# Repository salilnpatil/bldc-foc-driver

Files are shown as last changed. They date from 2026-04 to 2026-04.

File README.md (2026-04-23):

# BLDC Field-Oriented Control Driver

A custom three-phase inverter board and closed-loop firmware for driving a brushless DC (BLDC) motor using **Field-Oriented Control (FOC)**. Developed as my final-year B.Tech thesis and deployed as the pitch-axis actuator of a gimbal demonstrator: an external RC-style PWM signal commands a target angle, and the motor tracks it smoothly through a 3:1 gear reduction.

<p align="center">
  Driver tracking an external PWM setpoint on a BLDC gimbal
</p>

## Stack at a glance

| Layer | Choice |
| --- | --- |
| MCU | STM32G431 (Cortex-M4F + CORDIC coprocessor) |
| Commutation | 6-PWM, voltage-mode FOC ([SimpleFOC](https://simplefoc.com/)) |
| Position sensor | MA730 14-bit magnetic encoder (SPI) |
| Power stage | 3× half-bridge, TI N-channel MOSFETs |
| Setpoint input | RC-style PWM (timer input capture) |
| PCB tool | Autodesk EagleCAD |
| Bus voltage | 12 V (nominal) |

## Visuals

| PCB layout | Wiring diagram |
| --- | --- |
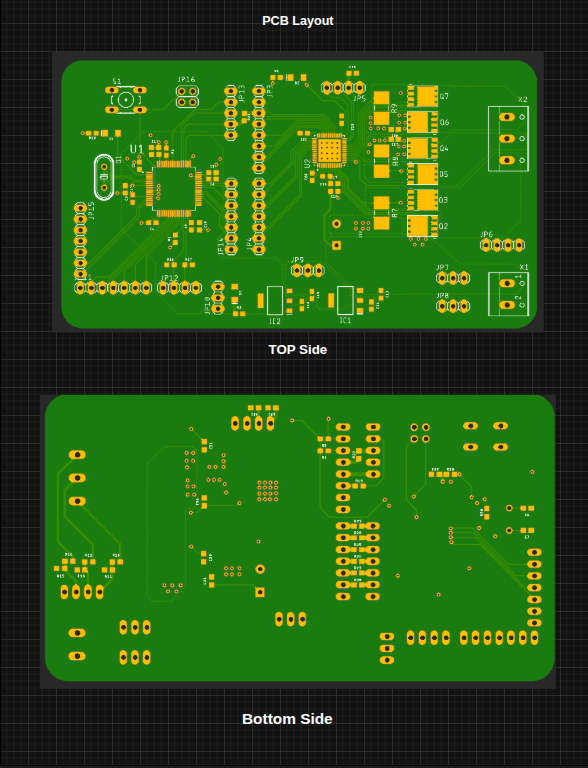
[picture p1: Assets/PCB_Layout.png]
PCB layout
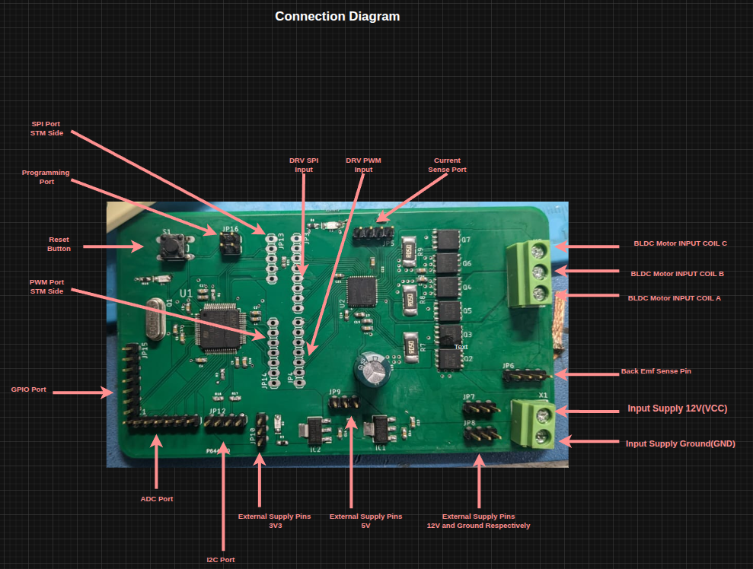
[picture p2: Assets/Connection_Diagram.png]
Wiring
|  |  |

Communication interface:

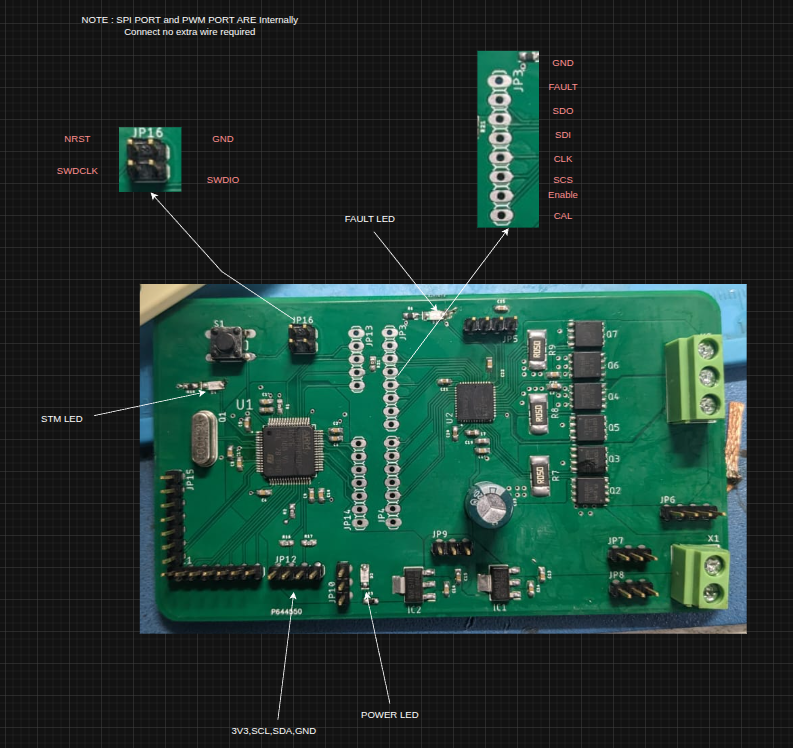
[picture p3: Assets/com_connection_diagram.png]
Communication wiring


## Repository layout

```
.
├── Assets/                              Demo GIF, connection diagrams, PCB render, final paper
├── Hardware_assets/
│   ├── Design_FIle(EagleCad)/           EagleCAD .brd + .sch sources
│   ├── Schematic/                       Exported PDF schematic
│   ├── Gerber_file/                     Fabrication-ready Gerbers (.zip)
│   └── BOM_&_Component_selection/       MOSFET trade-off spreadsheet
├── Firmware/
│   └── bldc-doc-driver/                 Arduino sketch (SimpleFOC on STM32G4)
└── README.md
```

## Hardware design

The board is a three-phase inverter built around three half-bridges of TI N-channel power MOSFETs, with an MA730 magnetic encoder front-end and a PWM-input pin exposed to an off-board receiver. A mechanical limit switch on the pitch axis provides a repeatable zero for homing.

**MOSFET selection** — the workbook in `Hardware_assets/BOM_&_Component_selection/` compares two TI candidates evaluated for the low-side/high-side switches:

| Part | Vds | Id | Rds(on) max | Qg | Notes |
| --- | --- | --- | --- | --- | --- |
| `CSD18510Q5B` | 40 V | 42 A | 1.2 mΩ | 118 nC | Lower Qgd, lower voltage headroom |
| `CSD18536KCS` | 60 V | 200 A | 1.3 mΩ | 108 nC | Higher Vds margin, much higher current rating |

Both sit at roughly 1.2–1.3 mΩ Rds(on), so the choice comes down to voltage headroom above the 12 V bus and thermal budget rather than conduction loss.

**Design artefacts**

- EagleCAD sources — [`Hardware_assets/Design_FIle(EagleCad)/Layout_Design_File.sch`](Hardware_assets/Design_FIle(EagleCad)/Layout_Design_File.sch), [`Schematic_Design_File.brd`](Hardware_assets/Design_FIle(EagleCad)/Schematic_Design_File.brd)
- Schematic PDF — [`Hardware_assets/Schematic/Final_Schematic.pdf`](Hardware_assets/Schematic/Final_Schematic.pdf)
- Gerbers — [`Hardware_assets/Gerber_file/Final_Gerber_File.zip`](Hardware_assets/Gerber_file/Final_Gerber_File.zip)

## Firmware

Sketch: [`Firmware/bldc-doc-driver/bldc-doc-driver.ino`](Firmware/bldc-doc-driver/bldc-doc-driver.ino).

**Control law** — SimpleFOC angle-control cascade: `angle (P) → velocity (PI) → q-axis voltage`. Torque mode is `TorqueControlType::voltage`, pole pairs are set to 7, and the motor voltage limit is clamped to `V_PSU / 2` for headroom.

**Parameters** (from the sketch)

| Define / field | Value |
| --- | --- |
| `V_PSU`, `V_LIMIT` | 12.0 V |
| `GEAR_REDUCTION` | 3 (pitch axis) |
| `ACCESSIBLE_ANGLE` | 3.00 rad of mechanical pitch travel |
| `PWM_IN_MIN` / `PWM_IN_MAX` | 4.94 % / 10.06 % duty (≈1.0–2.0 ms pulses) |
| `PID_velocity` P / I / D | 0.2 / 4 / 0 |
| `P_angle.P` | 10 |
| `velocity_limit` | 50 rad/s |

**Startup sequence**

1. Bring up the debug serial (`Serial3`, 115200), the STM32G4 CORDIC unit, the PWM input capture, and the MA730 sensor.
2. Configure driver + motor, run SimpleFOC `initFOC()` electrical alignment.
3. **Homing** — drive the motor slowly toward the limit switch; when it trips, snapshot the encoder angle as `max_angle`, compute `min_angle = max_angle − (ACCESSIBLE_ANGLE × GEAR_REDUCTION)`.
4. Build a linear mapper from input PWM duty `[4.94 %, 10.06 %]` onto `[min_angle, max_angle]`.

**Main loop** — `motor.loopFOC()` runs the current/voltage inner loop; each iteration the PWM-input duty is sampled, mapped to a target angle, clamped to the calibrated travel, and passed to `motor.move(target_angle)`.

### Library dependencies

- [SimpleFOC](https://github.com/simplefoc/Arduino-FOC) — `BLDCMotor`, `BLDCDriver6PWM`
- [SimpleFOC Drivers](https://github.com/simplefoc/Arduino-FOC-drivers) — `MagneticSensorMA730`, `STM32PWMInput`, `STM32G4CORDICTrigFunctions`, `STM32FlashSettingsStorage`
- [Arduino core for STM32 (stm32duino)](https://github.com/stm32duino/Arduino_Core_STM32) — board target: **Generic STM32G4 series / STM32G431xx**

### Build & flash (Arduino IDE)

1. Install Arduino IDE 2.x and the **STM32** boards package following stm32duino's instructions.
2. From Library Manager, install `SimpleFOC` and `SimpleFOC Drivers`.
3. Open `Firmware/bldc-doc-driver/bldc-doc-driver.ino`.
4. Board → *Generic STM32G4 series*; part → *STM32G431xx*; upload method → *STM32CubeProgrammer (SWD)* via an ST-Link.
5. Compile and flash.

### Known gaps / roadmap

- **STM32CubeIDE port** — planned. A HAL/LL implementation in STM32CubeIDE (native 6-PWM timer configuration, ADC-based phase current sensing, CORDIC-accelerated Park/Clarke) is on the roadmap as a production-grade replacement for the Arduino prototype. Not yet in-tree.

## Research paper

Full write-up covering FOC theory, hardware design rationale, and results: [`Assets/Final_Paper.pdf`](Assets/Final_Paper.pdf).

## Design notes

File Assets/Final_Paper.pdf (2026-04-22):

4

## Abstract-

This paper presents a comprehensive study on the Field-Oriented Control (FOC) of Brushless DC (BLDC) motors utilizing the DRV8323RS motor driver. BLDC motors offer several advantages over traditional brushed DC motors, including higher efficiency, longer lifespan, and smoother operation. FOC is a sophisticated control technique that optimizes the performance of BLDC motors by decoupling the torque and flux components, allowing for precise control of motor speed and torque.The DRV8323RS is a three-phase gate driver with integrated protection features, making it an ideal choice for driving BLDC motors in various applications. This research focuses on the implementation and performance evaluation of FOC using the DRV8323RS motor driver. The paper begins with an overview of BLDC motor principles, FOC theory, and the features of the DRV8323RS motor driver. The methodology section outlines the hardware setup, including the motor, driver, microcontroller, and other peripheral components. The software development process for FOC implementation is detailed, covering algorithms for rotor position estimation, current control, and speed regulation. Experimental results are presented to validate the effectiveness of FOC control using the DRV8323RS driver. Performance metrics such as speed response, torque ripple, and efficiency are evaluated under various operating conditions and compared with traditional control methods. Additionally, the paper discusses practical considerations and challenges encountered during the implementation, including parameter tuning, sensor selection, and system integration. Recommendations for optimizing FOC performance and future research directions are also provided.In conclusion, this research demonstrates the feasibility and benefits of employing FOC with the DRV8323RS motor driver for precise and efficient control of BLDC motors. The findings contribute to the advancement of motor control techniques and have implications for a wide range of industrial and automotive applications.

5

## INDEX

Sr No | Title | Page No.
1 | Introduction | 7
2 | Literature Review | 8
3 | System Description | 9
4 | Methodology | 10-14
5 | Software Implementation | 15
6 | Experiments and Results | 16.17
7 | Conclusion | 18
8 | Future Scope | 19

6

## LIST OF FIGURES

Fig. | Caption | Page No.
1 | STM32F405 | 10
2 | Pinout of DRV8323RS | 11
3 | MOSFETS Diagram | 12
4 | Schematic of PCB | 13,14
5 | FOC control Loop | 15
6 | Features and board Images | 16,17

7

### 1. Introduction

The advent of Brushless DC (BLDC) motors has revolutionized various industries due to their inherent advantages such as higher efficiency, greater reliability, and lower maintenance requirements compared to traditional brushed DC motors. These motors find extensive applications in fields ranging from industrial automation to automotive propulsion systems. However, to fully harness the potential of BLDC motors, advanced control techniques are essential. Among these techniques, Field-Oriented Control (FOC) stands out for its ability to achieve precise speed and torque control, leading to enhanced performance and efficiency.
This paper focuses on the implementation and evaluation of FOC for BLDC motor control using the DRV8323RS motor driver. The DRV8323RS, a three-phase gate driver with integrated protection features, offers a robust solution for driving BLDC motors, making it an ideal choice for a wide range of applications.
The motivation behind this research stems from the increasing demand for efficient and precise motor control systems in various industries. By utilizing FOC in conjunction with the DRV8323RS motor driver, this study aims to address the need for optimized BLDC motor control solutions that can meet the evolving requirements of modern applications. The introduction section provides an overview of the key concepts and components involved in BLDC motor control. It starts by discussing the fundamental principles of BLDC motor operation, highlighting the differences between BLDC and brushed DC motors, and elucidating the advantages of BLDC motors. Subsequently, it introduces the concept of FOC and explains its significance in improving the performance of BLDC motors by decoupling the control of torque and flux.
Furthermore, the introduction outlines the features and capabilities of the DRV8323RS motor driver, emphasizing its role in facilitating the implementation of FOC control for BLDC motors. The integrated protection mechanisms of the DRV8323RS, such as overcurrent and overtemperature protection, ensure the safe and reliable operation of the motor system.
In summary, the introduction sets the stage for the subsequent sections of the paper by providing a comprehensive overview of the research objectives, the significance of FOC in BLDC motor control, and the suitability of the DRV8323RS motor driver for implementing FOC. The following sections will delve deeper into the methodology, experimental results, and discussions, culminating in conclusions and future research directions.

8

### 2. Literature Review

[1]The FOC algorithm has been implemented on a BLDC motor using the low-cost STM32F103C8T6 microcontroller. The STM32F103C8T6 microcontroller is able to calculate all algorithms and process data. In order to validate the FOC algorithm system and assess the performance of the STM32F103C8T6 microcontroller, a 350-watt BLDC motor on an electric bicycle was tested and compared with a Universal controller. The test has been conducted that the FOC controller was superior to the Universal controller in saving power. The required current is less in a steady state or in a peak state. So that the battery used will last longer. This is due to the use of the Space Vector Pulse Width Modulation (SVPWM) method, which increases the efficiency of 3-phase voltage generation on BLDC motor. In testing, it was also proven that FOC can rotate BLDC motor at low speeds and reduce torque ripple.
[2]The paper designs a high power brushless DC motor (BLDC) closed-loop control system, mainly including design of FOC drive circuit, H bridge drive circuit, Control of rotation direction for motor and speed detection circuit. In order to improve the performance of motor running, one adopts PID algorithm, through the tuning of parameters, the control exhibits very good performance. Experiments show that both hardware and software control algorithms are reliable, stable. The running performance of the system is robust before or after adding load. It describe the principles behind field orientated control method for brushless direct current motors using an absolute position sensor and to implement a working field orientated algorithm base motor controller using a microcontroller and complementing hardware. The work consists of text, pictures and tables describing the theoretical background, implementation and system verification.
[3] In this paper, the comparative performance analysis of Field oriented control (FOC) of Permanent magnet brushless DC (PMBLDC) motor using sinusoidal pulse width modulation (SPWM) and space vector pulse width modulation (SVPWM) techniques is presented. The primary focus of using field oriented control for motor is to control the motor parameters in d-q axes along with sinusoidal and space vector modulated pulses for voltage source inverter driving the BLDC motor. This vector control method improves the system performance along with high efficiency and low torque ripple thus making it suitable for finding applications in high performance variable frequency drives. The sensor less approach for rotor position sense provides an advantage of cost reduction with ease of implementation using digital signal controllers (DSCs) and microprocessors. The analysis of the system is realized using MATLAB/SIMULINK program. The simulation results show that the SVPWM based system has superior performance compared to SPWM system.
[4] Field Oriented Control (FOC) is a widely employed motor control methodology for Brushless DC (BLDC) motors. FOC requires an accurate measure of the rotor angular position for proper operation. Depending on how this rotor position is obtained, FOC can be implemented in either sensored mode or sensorless mode. Typically, sensored FOC employs position sensors to measure rotor angular position, whereas sensorless FOC estimates the rotor position using state observers based on currents, voltages and back electro motive forces (BEMF). This paper presents the first stage of a research aimed to identify an optimum observer type for a sensorless FOC, and it focuses in particular on the implementation of a Luenberger BEMF observer (LBO) based sensorless FOC system. Based on the mathematical formulation of the problem, the LBO was constructed to be a timevarying system, which introduced additional complexities when implementing the system in MATLAB. All simulations were carried out in the MATLAB Simulink environment according to predefined test criteria. The simulation results of the sensored FOC show accurate tracking of the reference speed and smooth transition dynamics, whereas the sensorless FOC simulations also indicate similar performance to the sensored case in general. However, a steady state speed ripple was noticed in the sensorless mode compared to sensored mode, along with increased settling times

9

### 3. System Description-

Entire system consists of custom BLDC motor driver PCB having DRV8323RS as and motor driver IC and stm32f405 microcontroller. The system is designed for 50w power rating. PCB is suitable for 80kv capacity BLDC motor. The control technique used for motion control is field orientation control. FOC operates on the principle of transforming the three-phase stator currents and voltages from the stationary reference frame (abc) to a rotating reference frame (dq), aligned with the rotor flux. This transformation simplifies the control problem by decoupling the torque-producing (d-axis) and magnetizing (q-axis) components. FOC system has 2 control loops – current loop and speed control loop. Current loop regulates the stator currents (Id, Iq) to track the desired reference values. Proportional-Integral (PI) controllers are typically used to maintain precise current control. Adjusts the reference values for Id and Iq to achieve the desired speed or torque command. The speed loop often includes a PI or Proportional-Integral-Derivative (PID) controller.

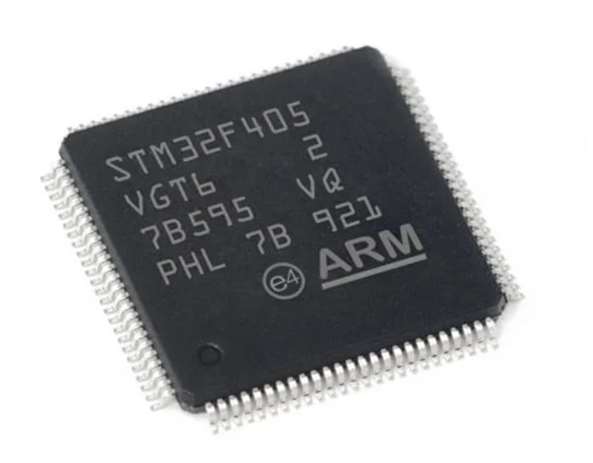
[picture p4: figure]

10

### 4. Methodology-

### 4.1 Schematic of PCB-

i. STM32F405-
STM32F405 is an ARM Cortex-M4 microcontroller from the STM32 family of devices by STMicroelectronics. It has a 32-bit ARM Cortex-M4 core running at up to 168 MHz, 1 MB of Flash memory, 192 KB of RAM, and various peripherals such as USB, Ethernet, and CAN.

Fig No.1 – STM32F405
Performance Parameters-
- 32-bit ARM Cortex-M4 core with FPU;
- Operating frequency up to 168 MHz;
- 1.25 DMIPS/MHz (Dhrystone 2.1) performance;
- Up to 1 MB Flash, 192KB RAM;
- Operating voltage range of 2.0V – 3.6V;
- 216MHz maximum CPU frequency;
- 64 ~ 144 pinout: 4 x 4.2 mm;
- 96-bit unique ID;
- 12-bit ADC with 16 channels;
- 17 timers including 32-bit with PWM;
- 96 line general purpose I/O pins;
- 1.25 DMIPS/MHz performance;
- 8/16/32-bit external bus interface;
- x I2C, 3 x SPI, 6 x USART, 2 x CAN, USB 2.0 FS OTG;
- Debug support: JTAG and SWD interface with 4-wire JTAG.

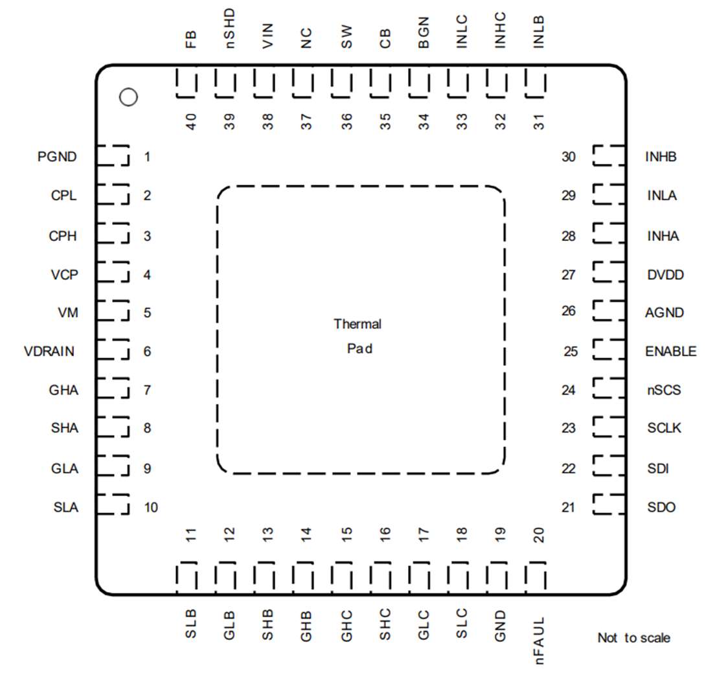
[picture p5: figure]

11

ii. DRV8323RS-The DRV832x family of devices is an integrated gate driver for three-phase applications. The devices provide three half-bridge gate drivers, each capable of driving high-side and low-side N-channel power MOSFETs. The DRV832x generates the correct gate drive voltages using an integrated charge pump for the high-side MOSFETs and a linear regulator for the low-side MOSFETs. The Smart Gate Drive architecture supports peak gate drive currents up to 1-A source and 2-A. The DRV832x can operate from a single power supply and supports a wide input supply range of 6 to 60 V for the gate driver and 4 to 60 V for the optional buck regulator.

Fig No.2 – Pinout of DRV8323RS

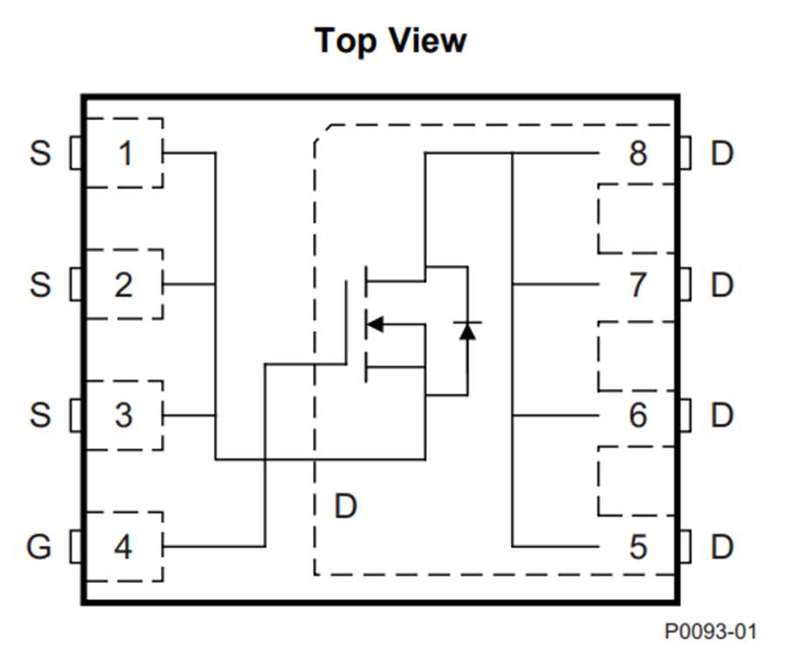
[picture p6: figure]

12

iii. CSD18510Q5B N- Channel MOSFET-

40-V, 0.79-mΩ, SON 5-mm × 6-mm NexFET power MOSFET has been designed to minimize losses in power conversion applications.

Fig No.- 3 MOSFET Top View

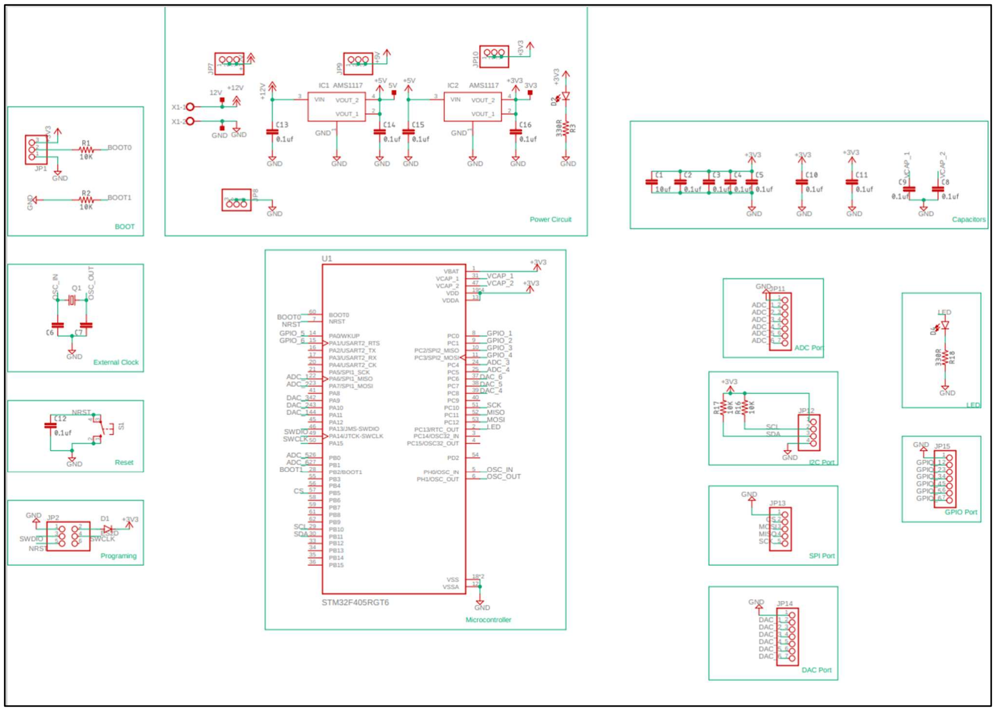
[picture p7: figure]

13

4.2- Schematic of PCB-

1.Microcontroller side PCB-
Figure Number 4 represents the schematic of microcontroller circuit of PCB. It consists of
- Capacitor bank for filtration of signal.
- 2 Low Dropout Regulators providing 3.3v and 5v respectively.
- 16Mhz crystal oscillator for clock generation.
- Different types of GPIO ports

Fig. 4 – Microcontroller schematic

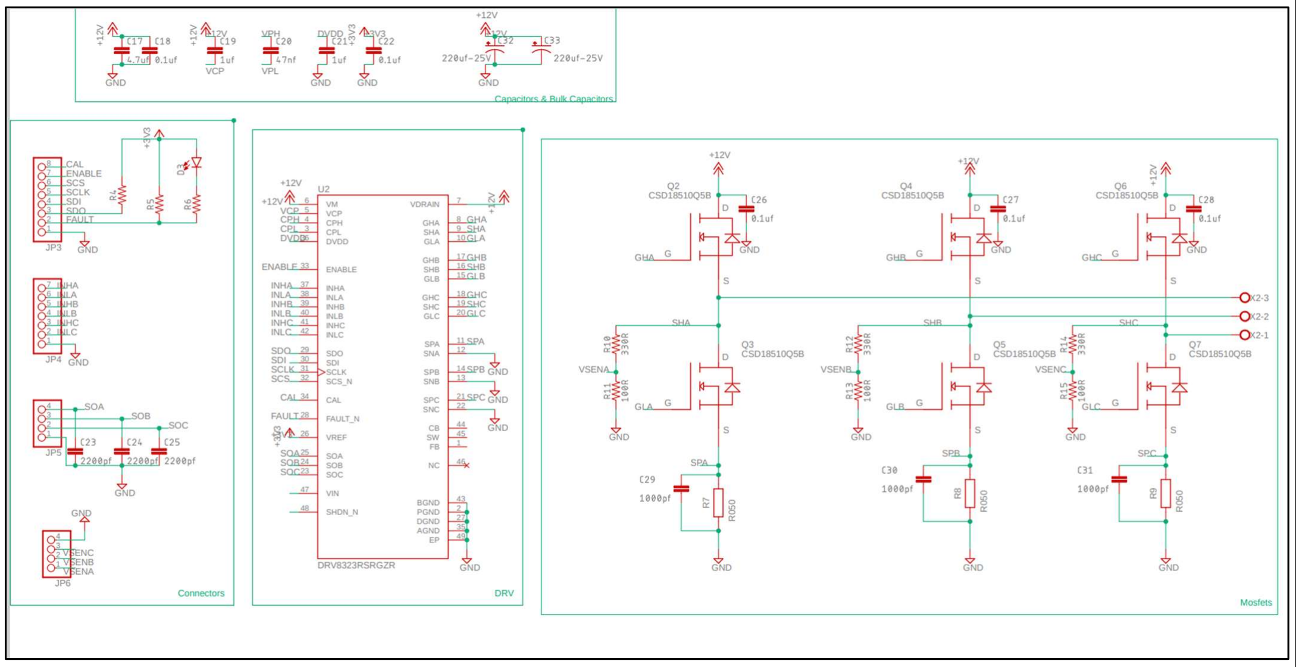
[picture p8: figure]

14

II. Motor driver circuit-

This schematic consists of-

### 1. Bulk Capacitors for power distribution

2. 6 channel MOSFET drive

### 3. DRV8323RS motor driver IC 4. Internal current sensor for current sensing of each phase 5. Voltage divider network for checking voltage across each phase

Fig No.5- Motor driver schematic

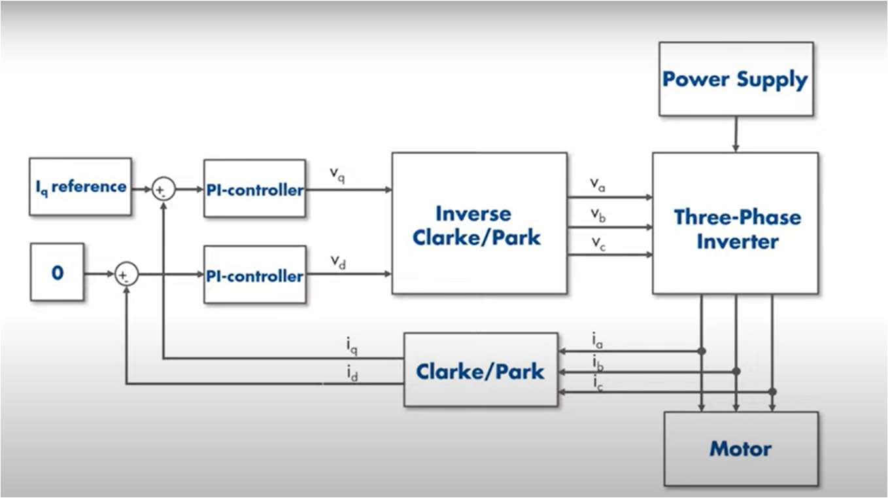
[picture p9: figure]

15

### 5. Software Implementation-

Existing Motor Control/Driving Techniques:
1. Trapezoidal control: Also known as 6-step control, this is the simplest algorithm .For each of the 6 commutation steps, a current path is formed between a pair of windings, leaving the third winding disconnected. This method generates high torque ripple, leading to vibration, noise, and poorer performance compared to other algorithms.
2. Sinusoidal control: Also known as voltage-over- frequency commutation, sinusoidal control overcomes many of the issues involved with trapezoidal control by supplying smoothly (sinusoidal) varying current to the 3 windings, thus reducing the torque ripple and offering a smooth rotation. However, these time-varying currents are controlled using basic PI regulators, which lead to poor performance at higher speeds.
3. Field Oriented Control (FOC): Also known as vector control, FOC provides better efficiency at higher speeds than sinusoidal control. It also guarantees optimized efficiency even during transient operation by perfectly maintaining the stator and rotor fluxes FOC also gives better performance on dynamic load changes when compared to all other techniques. Field Oriented Control is one of the methods used in variable frequency drives or variable speed drives to control the torque (and thus the speed) of three-phase AC electric motors by controlling the current .With FOC, the torque and the flux can be controlled independently .FOC provides faster dynamic response than is required for applications like washing machines. There is no torque ripple and smoother, accurate motor control can be achieved at low and high speeds using FOC. The torque of an induction motor is at a maximum when the stator and the rotor magnetic fields are orthogonal to each other. In FOC, the stator currents are measured and adjusted so that the angle between the rotor and stator flux is 90 degrees to achieve the maximum torque.

Fig No.6- FOC control loop

The steps involved in sensored FOC are as follows:
Step 1: Two of the three stator phase currents are measured and the third current is determined using Kirchoff’’s current relation, Ia + Ib + Ic = 0 Where Ia, Ib, and Ic are phase currents
Step 2:The three phase currents are converted into a 2-axis coordinate system from the 3-axis system of the stator, using a Clarke transformation, Where Ia and ß are the stator currents transformed to the 2- axis coordinate system.
Step 3: The components along the 2-axis of the stator currents are time varying in nature and to track them using traditional PIs is complex. Rather, the stationary reference is rotated based on the rotor position (which is determined with the help of sensors or from back EMF) to a rotary reference where the components along the axis remain constant and traditional PI controllers can be used to counter any error. This rotation is done using a Park transformation, Where Id and Iq are the in-phase and quadrature phase stator currents from the rotor perspective
Step 4: Once the vectors have become time invariant, we can compare the corresponding axis vectors with the reference and use a PI controller (see equation below) for each axis to determine the error correction signal. The Id reference controls the rotor magnetizing flux. The Iq reference controls the torque output of the motor
Step 5: The corresponding outputs of the PI controllers are then passed through an inverse Park and Clarke transformation to convert them back to the 3-phase stator reference.
Step 6: With the 3-phase reference signals generated, the PWM is modulated using Space Vector Modulation.

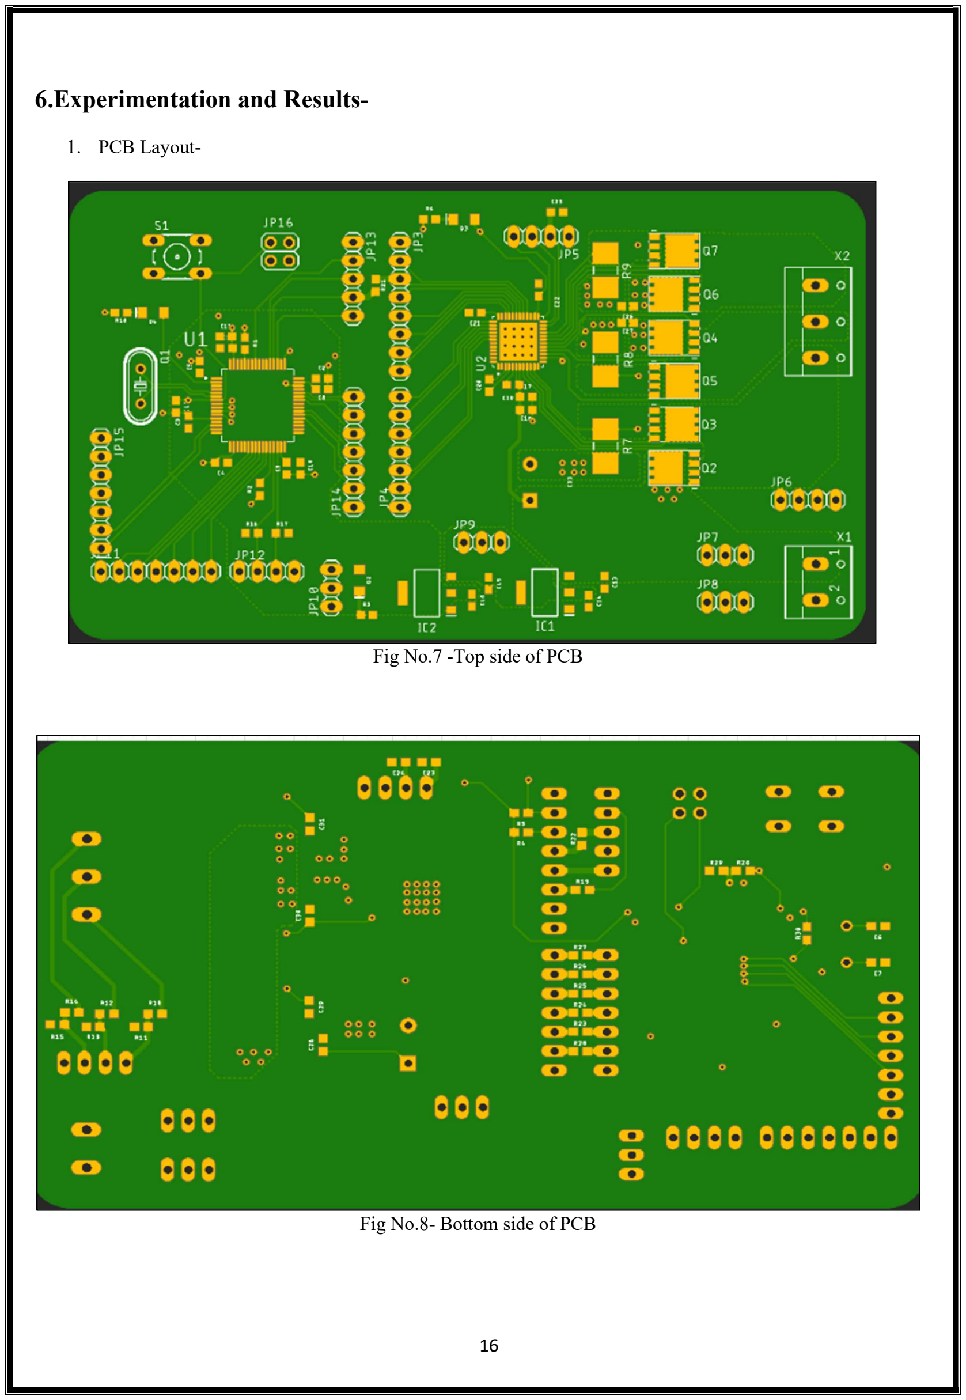
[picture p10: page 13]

16

6.Experimentation and Results-

### 1. PCB Layout-

Fig No.7 -Top side of PCB

Fig No.8- Bottom side of PCB

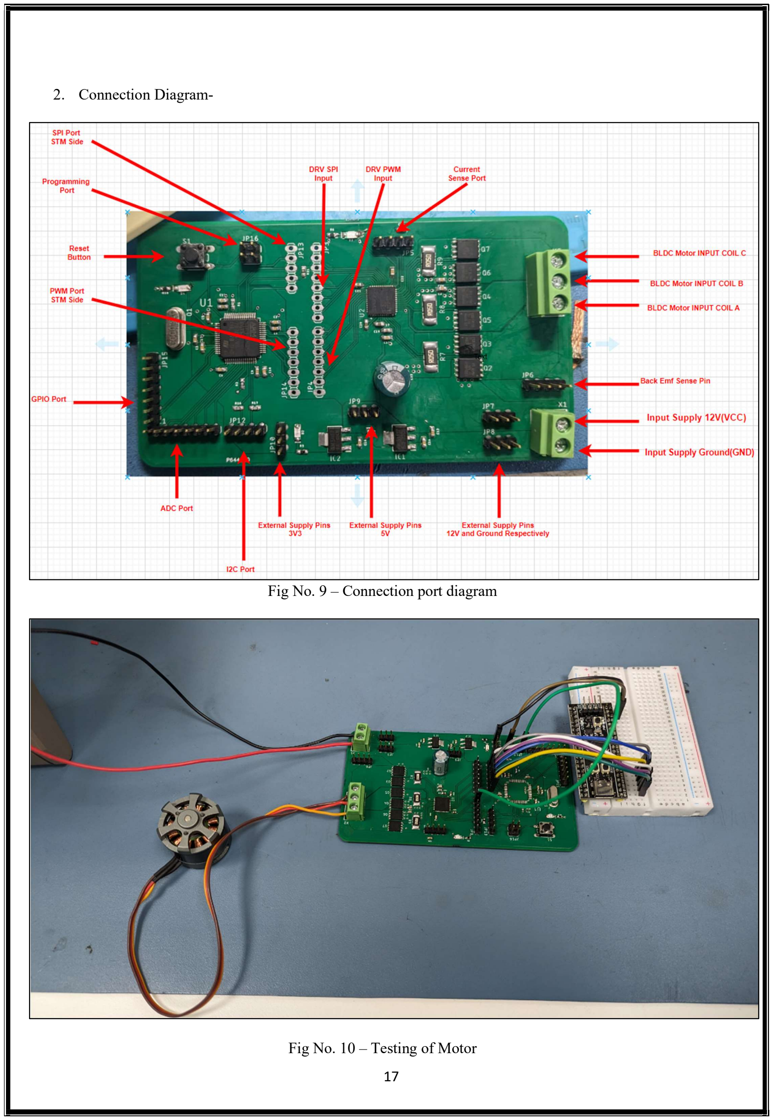
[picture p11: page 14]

17

### 2. Connection Diagram-

Fig No. 9 – Connection port diagram

Fig No. 10 – Testing of Motor

18

### 6. Conclusion

In this Project, we have Disign & Developped BLDC motor driver specifically for Field-Oriented Control (FOC). Through a combination of innovative hardware design and advanced control algorithms, our driver offers several significant advantages over existing solutions in terms of efficiency, performance, flexibility and cost effectiveness.

Our experimental results demonstrate that the proposed BLDC motor driver achieves superior speed and torque control accuracy, reduce torque ripple, even under varying load conditions. The implementation of FOC allows for smooth and precise operation across a wide range of speeds, enabling applications that demand high responsiveness and reliability.

Furthermore, the modular architecture of our driver facilitates easy integration into diverse systems and platforms, making it adaptable to various industrial and commercial applications. The scalability and robustness of our design lay a solid foundation for future developments and enhancements in BLDC motor control technology.

In conclusion, our Project contributes to the advancement of BLDC motor control by introducing a state-of-theart driver solution tailored for FOC. The performance and versatility of our driver hold great promise for improving the efficiency and effectiveness of electric propulsion systems in numerous fields, including automotive, aerospace, robotics, and renewable energy.

Looking ahead, we envision further refinements and optimizations to enhance the capabilities and applicability of our BLDC motor driver, paving the way for even greater innovation and impact in the realm of electric motor control.

19

### 7. Future Scope

1.Torque Ripple Reduction:Despite achieving notable reductions in torque ripple, further refinement of our control algorithms and hardware design could lead to even more significant improvements. Investigating advanced control strategies, such as predictive algorithms or adaptive tuning techniques, may help mitigate torque ripple to an even greater extent.

2.Integration of Advanced Sensors: Currently We're Using Current Sense sensor and magnetic encode. Incorporating additional sensors, such as strain gauges or vibration sensors, into our motor driver system could enable real-time monitoring of motor performance and health. By leveraging this additional data, we can develop more robust fault detection and predictive maintenance algorithms, enhancing the reliability and longevity of BLDC motor-driven systems.

3.Adaptive Control Strategies: Exploring adaptive control strategies that can dynamically adjust control parameters based on changing operating conditions could further optimize motor performance. Adaptive algorithms capable of adapting to variations in load, temperature, and other environmental factors could enhance efficiency and responsiveness across a broader range of operating conditions.

4.Hardware Optimization: Continued advancements in power electronics and semiconductor technologies offer opportunities for further optimization of the hardware components in our motor driver. Exploring novel materials, packaging techniques, and circuit topologies could lead to improvements in power density, thermal management, and overall system efficiency.

5.Application-Specific Implementations: Tailoring our motor driver design to specific application domains, such as robotics, aerospace, or renewable energy systems, could unlock new opportunities for innovation and impact. Customizing control algorithms, communication interfaces, and form factors to meet the unique requirements of each application could result in more specialized and efficient solutions.

6.Integration with Emerging Technologies:As emerging technologies such as Internet of Things (IoT) and artificial intelligence continue to evolve, exploring synergies between these technologies and BLDC motor control could yield novel solutions with enhanced functionality and intelligence. Integrating our motor driver with IoT platforms for remote monitoring and control or incorporating machine learning algorithms for predictive optimization are promising areas for future exploration.

In summary, the future scope of our Project encompasses a broad range of opportunities for further innovation and advancement in BLDC motor control. By continuing to push the boundaries of technology and exploring new frontiers, we can further enhance the performance, efficiency, and reliability of BLDC motor-driven systems, driving progress towards a more sustainable and interconnected future

20

### 8. References

[1] Field Oriented Control Implementation on BLDC Motor Controller with PI and SVPWM using STM32F103C8T6 Sweety Kumari, balasaheb Annasaheb Kardile and Khizar Ahmed Pathan
[2] Design of FOC Brushless DC (BLDC) Motor Controller 1Rohita Lokhande, Prof. Priyanka Dukre,
IJSDR ,2020
[3] Comparative analysis of Field oriented control of BLDC motor using SPWM and SVPWM techniques Meghana N Gujjar , Pradeep Kumar , IEEE 2017
[4] Design of a Sensorless Field Oriented Control Drive for Brushless DC Motors, University of Manchester, 2022
[5] A Novel Space Vector PWM Technique for Field Oriented Control of BLDC Motor Drive ,Vinoth Kumar, S. Muruganand, IEEE 2018
[6] Implementation of FOC for BLDC motor using DSP TMS320F28027 Harpreet Kaur, Gurpreet Singh, Pushpinder Singh, IEEE,2020
[7] Performance comparison of PI and Fuzzy logic controllers for BLDC motor drive using FOC technique Manoj Kumar Patel, Sanjeev Gupta, Rajesh Meshram, IEEE 2021
[8] Design and Implementation of FOC for BLDC Motor Drive with Low-Cost Microcontroller Ashish J. Kothari, Sunil R. Chaudhari, IJRCT 2018

21

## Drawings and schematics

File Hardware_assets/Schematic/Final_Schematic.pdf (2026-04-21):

# 12VGND

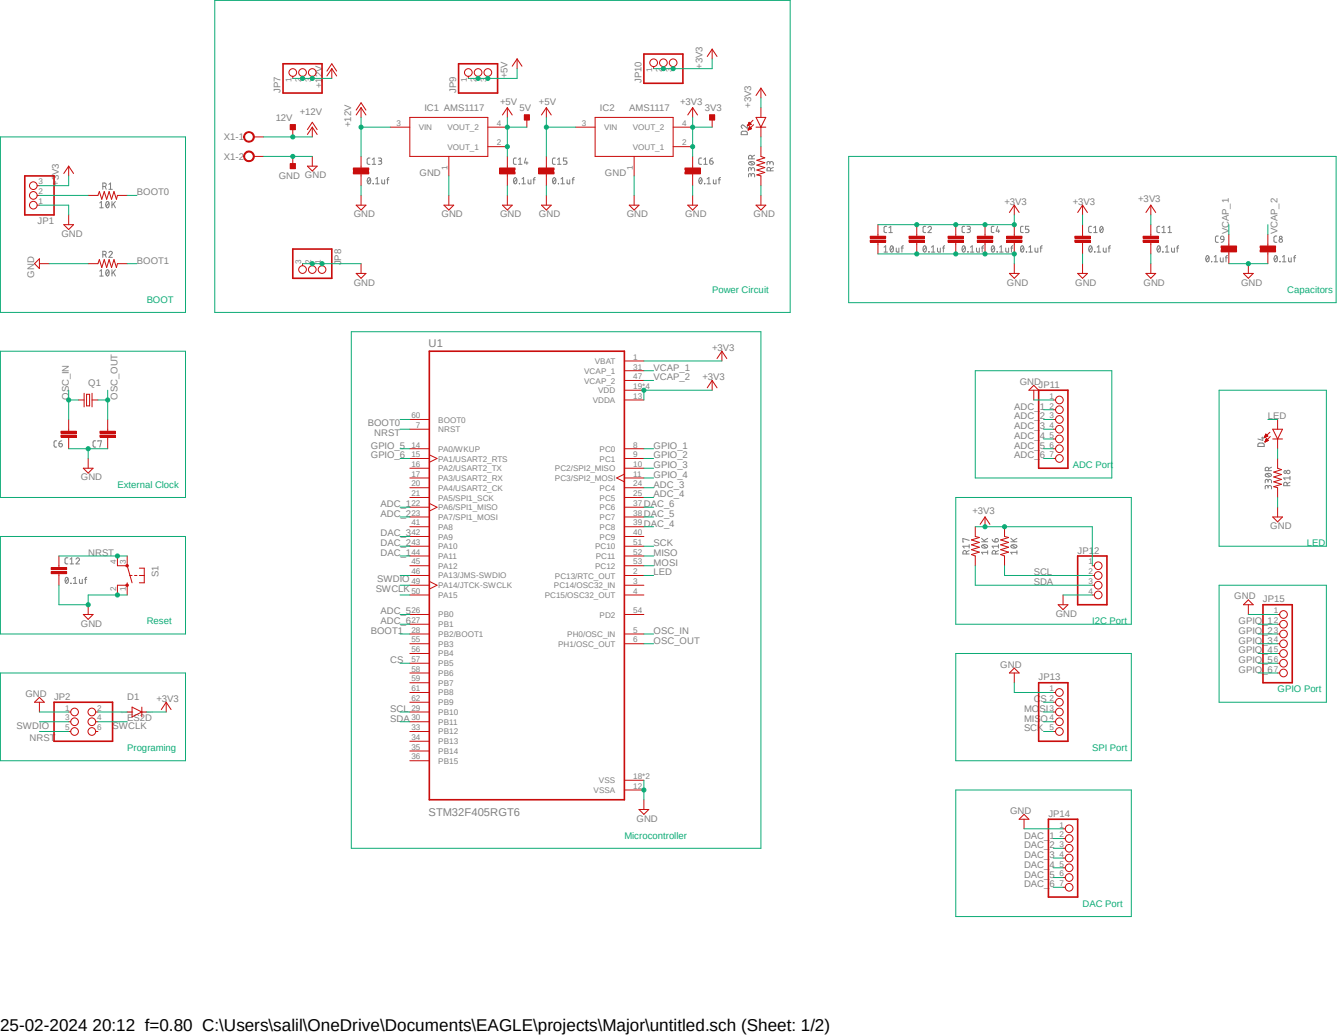
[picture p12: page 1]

25-02-2024 20:12 f=0.80 C:\Users\salil\OneDrive\Documents\EAGLE\projects\Major\untitled.sch (Sheet: 1/2)

CPL 3 | CPH 4 | VCP 5 | VM 6 | VDRAIN | 7 GHA | 8 SHA | 9 GLA | 10 SPA | 11 SNA | 12 SNB | 13 SPB | 14 GLB | 15 SHB | 16 GHB | 17 GHC | 18 SHC | 19 GLC | 20 SPC | 21 SNC | 22 SOC 23 | SOB 24 | SOA 25 | VREF 26 | DGND | 27 FAULT_N 28 | ENABLE 33 | CAL 34 | AGND | 35

# CAL FAULT

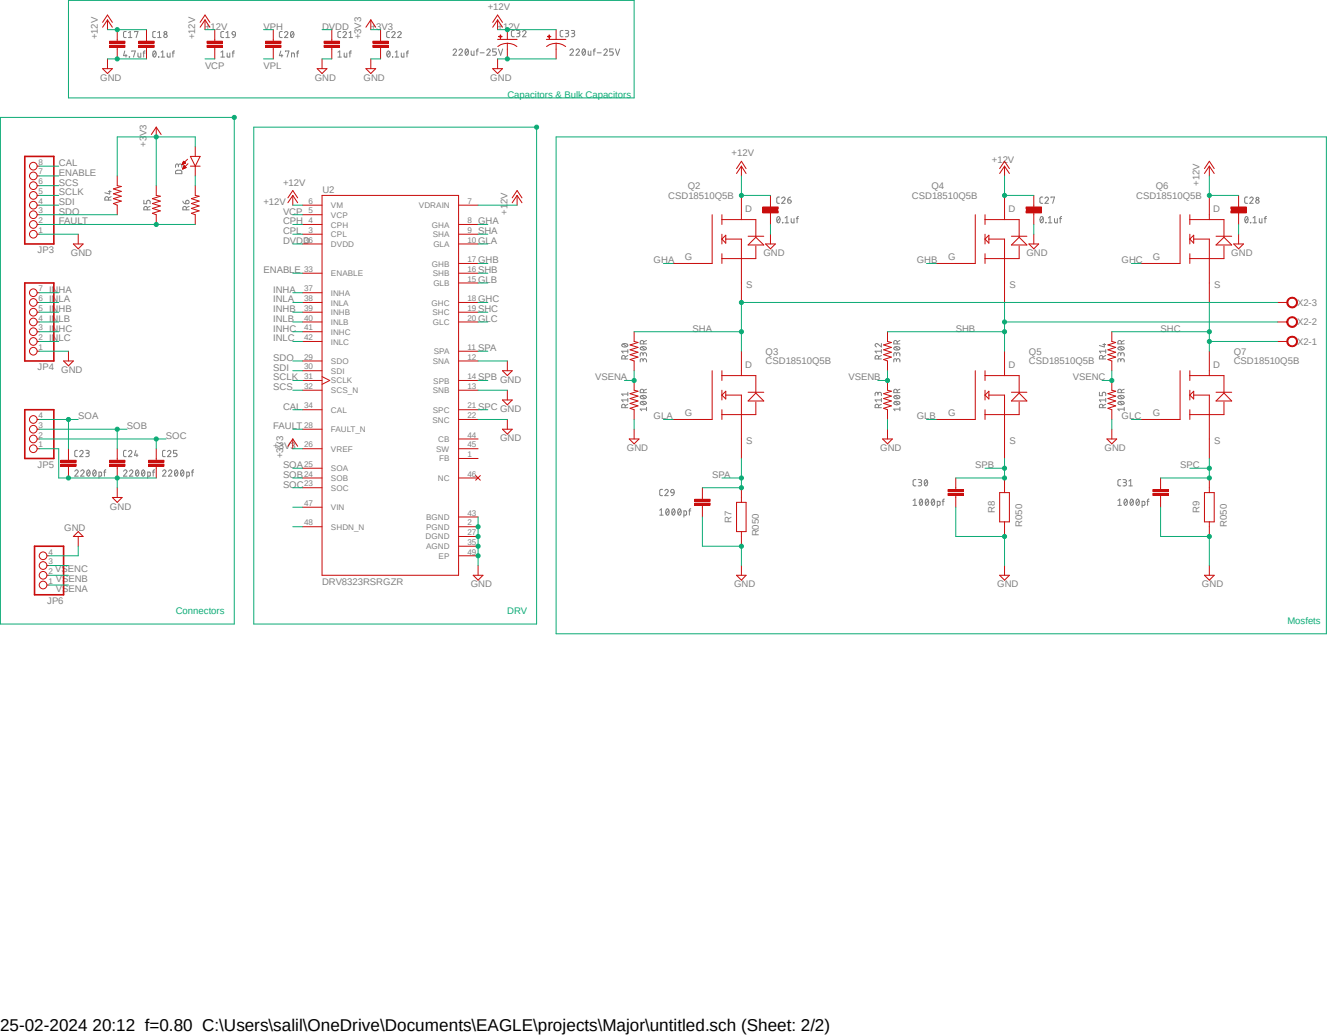
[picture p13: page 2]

25-02-2024 20:12 f=0.80 C:\Users\salil\OneDrive\Documents\EAGLE\projects\Major\untitled.sch (Sheet: 2/2)

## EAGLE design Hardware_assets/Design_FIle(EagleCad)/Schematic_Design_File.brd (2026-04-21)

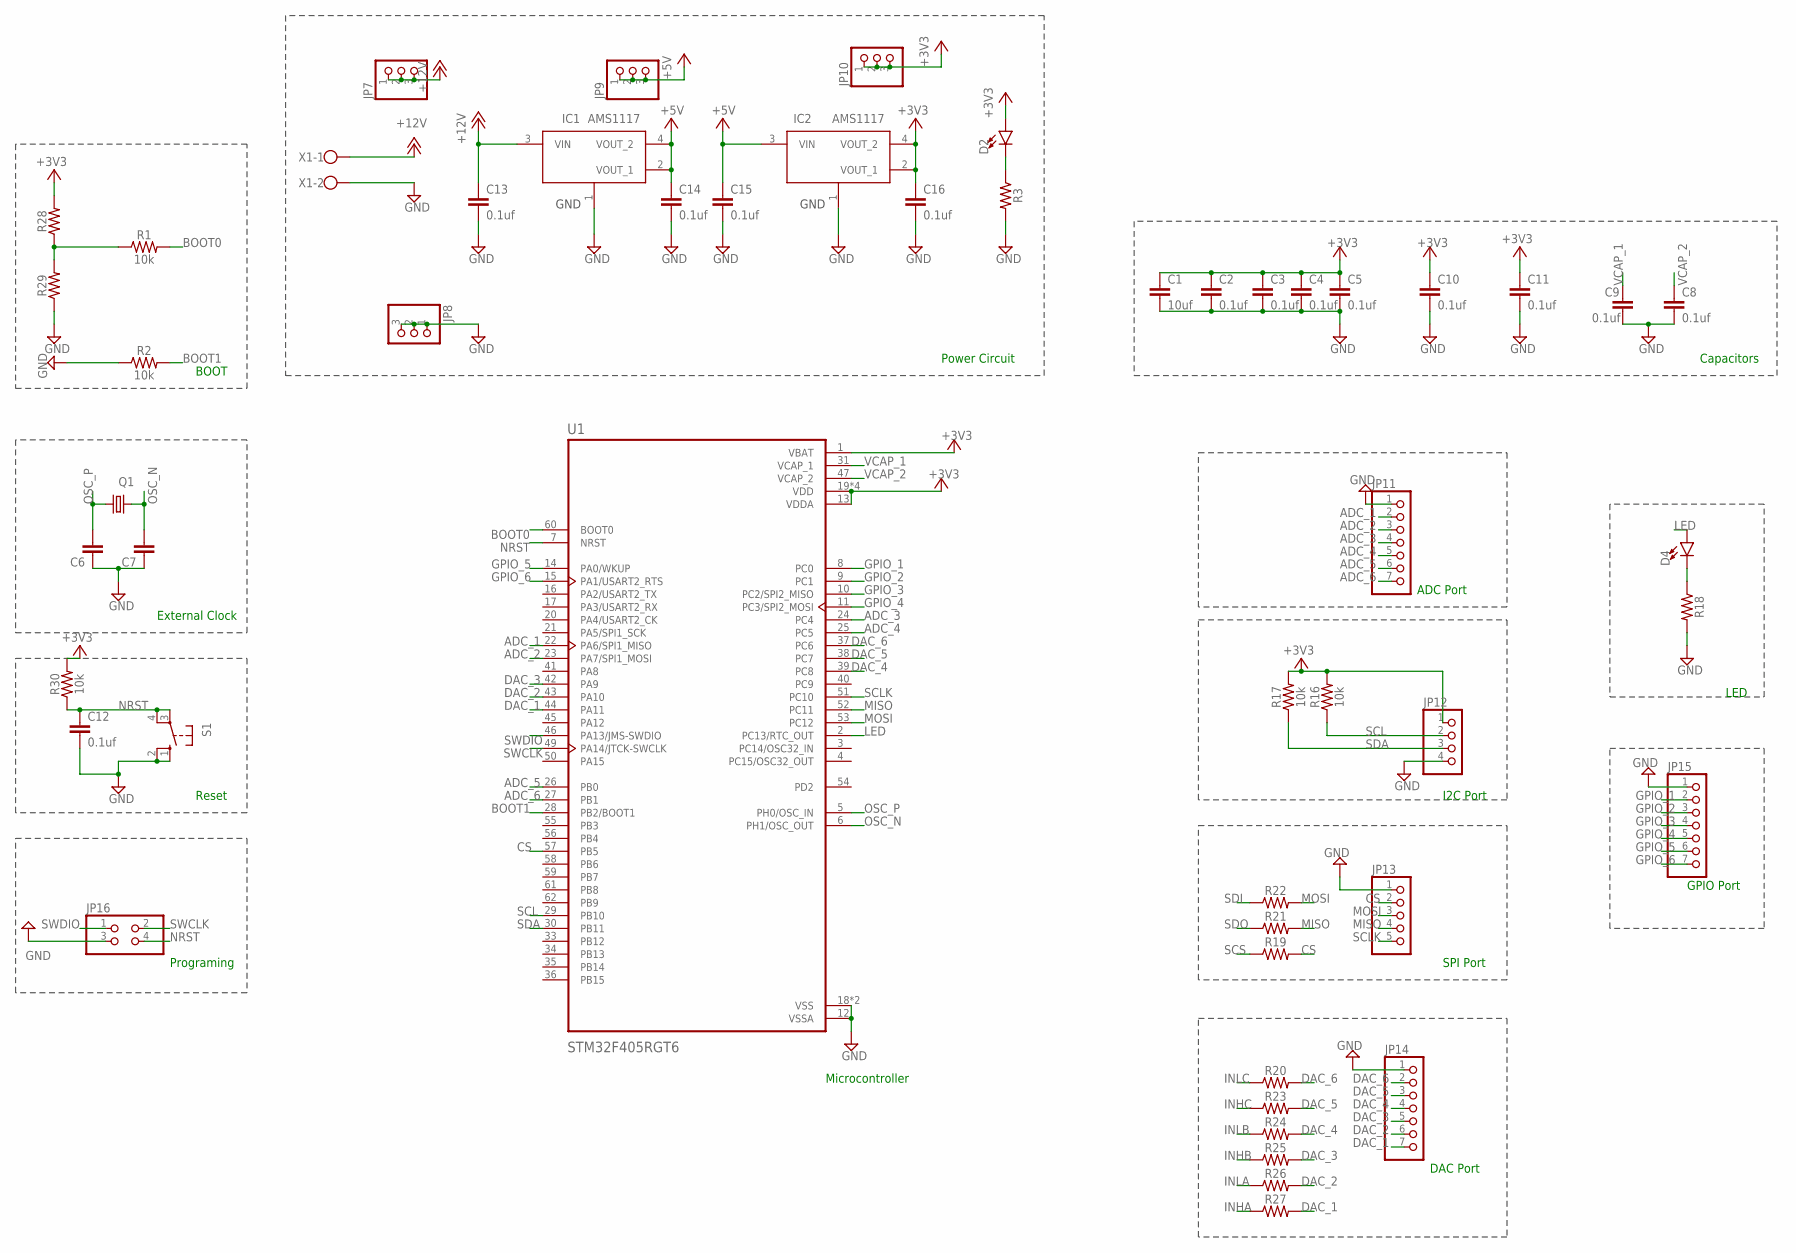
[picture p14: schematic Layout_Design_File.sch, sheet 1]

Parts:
C1: 10uf; 0603
C2, C3, C4, C5, C8, C9, C10, C11, C12, C13, C14, C15, C16: 0.1uf; 0603
C6, C7: CAP-0603; 0603
D2, D4: LED1206; LED-1206
IC1, IC2: AMS1117; SOT229P700X180-4N
JP7, JP8, JP9, JP10: PINHD-1X3; 1X03
JP11, JP14, JP15: PINHD-1X7; 1X07
JP12: PINHD-1X4; 1X04
JP13: PINHD-1X5; 1X05
JP16: PINHD-2X2; 2X02
Q1: CRYSTALHC49S; HC49/S
R1, R2, R16, R17, R30: 10k; 0603
R3, R18, R19, R20, R21, R22, R23, R24, R25, R26, R27, R28, R29: 0603
S1: 10-XX; B3F-10XX
U1: STM32F405RGT6; QFP50P1200X1200X160-64N
X1: W237-102

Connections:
+3V3: C1.1, C2.1, C3.1, C4.1, C5.1, C10.1, C11.1, C16.1, D2.A, IC2.2 (VOUT_1), IC2.4 (VOUT_2), JP10.1, JP10.2, JP10.3, JP12.1, R16.2, R17.2, R28.2, R30.2, U1.1 (VBAT), U1.13 (VDDA), U1.19 (VDD), U1.32 (VDD), U1.48 (VDD), U1.64 (VDD); also elsewhere on the board
+5V: C14.1, C15.1, IC1.2 (VOUT_1), IC1.4 (VOUT_2), IC2.3 (VIN), JP9.1, JP9.2, JP9.3
+12V: C13.1, IC1.3 (VIN), JP7.1, JP7.2, JP7.3, X1.1; also elsewhere on the board
ADC_1: JP11.2, U1.22 (PA6/SPI1_MISO)
ADC_2: JP11.3, U1.23 (PA7/SPI1_MOSI)
ADC_3: JP11.4, U1.24 (PC4)
ADC_4: JP11.5, U1.25 (PC5)
ADC_5: JP11.6, U1.26 (PB0)
ADC_6: JP11.7, U1.27 (PB1)
BOOT0: R1.2, U1.60 (BOOT0)
BOOT1: R2.2, U1.28 (PB2/BOOT1)
CS: JP13.2, R19.2, U1.57 (PB5)
DAC_1: JP14.7, R27.2, U1.44 (PA11)
DAC_2: JP14.6, R26.2, U1.43 (PA10)
DAC_3: JP14.5, R25.2, U1.42 (PA9)
DAC_4: JP14.4, R24.2, U1.39 (PC8)
DAC_5: JP14.3, R23.2, U1.38 (PC7)
DAC_6: JP14.2, R20.2, U1.37 (PC6)
GND: C1.2, C2.2, C3.2, C4.2, C5.2, C6.1, C7.1, C8.2, C9.2, C10.2, C11.2, C12.2, C13.2, C14.2, C15.2, C16.2, IC1.1 (GND), IC2.1 (GND), JP8.1, JP8.2, JP8.3, JP11.1, JP12.4, JP13.1, JP14.1, JP15.1, JP16.3, R2.1, R3.2, R18.2, R29.1, S1.1 (S), S1.2 (S1), U1.12 (VSSA), U1.18 (VSS), U1.63 (VSS), X1.2; also elsewhere on the board
GPIO_1: JP15.2, U1.8 (PC0)
GPIO_2: JP15.3, U1.9 (PC1)
GPIO_3: JP15.4, U1.10 (PC2/SPI2_MISO)
GPIO_4: JP15.5, U1.11 (PC3/SPI2_MOSI)
GPIO_5: JP15.6, U1.14 (PA0/WKUP)
GPIO_6: JP15.7, U1.15 (PA1/USART2_RTS)
INHA: R27.1; also elsewhere on the board
INHB: R25.1; also elsewhere on the board
INHC: R23.1; also elsewhere on the board
INLA: R26.1; also elsewhere on the board
INLB: R24.1; also elsewhere on the board
INLC: R20.1; also elsewhere on the board
LED: D4.A, U1.2 (PC13/RTC_OUT)
MISO: JP13.4, R21.2, U1.52 (PC11)
MOSI: JP13.3, R22.2, U1.53 (PC12)
unnamed: D2.C, R3.1
unnamed: D4.C, R18.1
unnamed: R1.1, R28.1, R29.2
NRST: C12.1, JP16.4, R30.1, S1.3, S1.4 (P1), U1.7 (NRST)
OSC_N: C7.2, Q1.2, U1.6 (PH1/OSC_OUT)
OSC_P: C6.2, Q1.1, U1.5 (PH0/OSC_IN)
SCL: JP12.2, R16.1, U1.29 (PB10)
SCLK: JP13.5, U1.51 (PC10); also elsewhere on the board
SCS: R19.1; also elsewhere on the board
SDA: JP12.3, R17.1, U1.30 (PB11)
SDI: R22.1; also elsewhere on the board
SDO: R21.1; also elsewhere on the board
SWCLK: JP16.2, U1.49 (PA14/JTCK-SWCLK)
SWDIO: JP16.1, U1.46 (PA13/JMS-SWDIO)
VCAP_1: C9.1, U1.31 (VCAP_1)
VCAP_2: C8.1, U1.47 (VCAP_2)

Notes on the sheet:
BOOT
External Clock
Reset
Programing
Power Circuit
Capacitors
Microcontroller
ADC Port
I2C Port
SPI Port
DAC Port
GPIO Port
LED

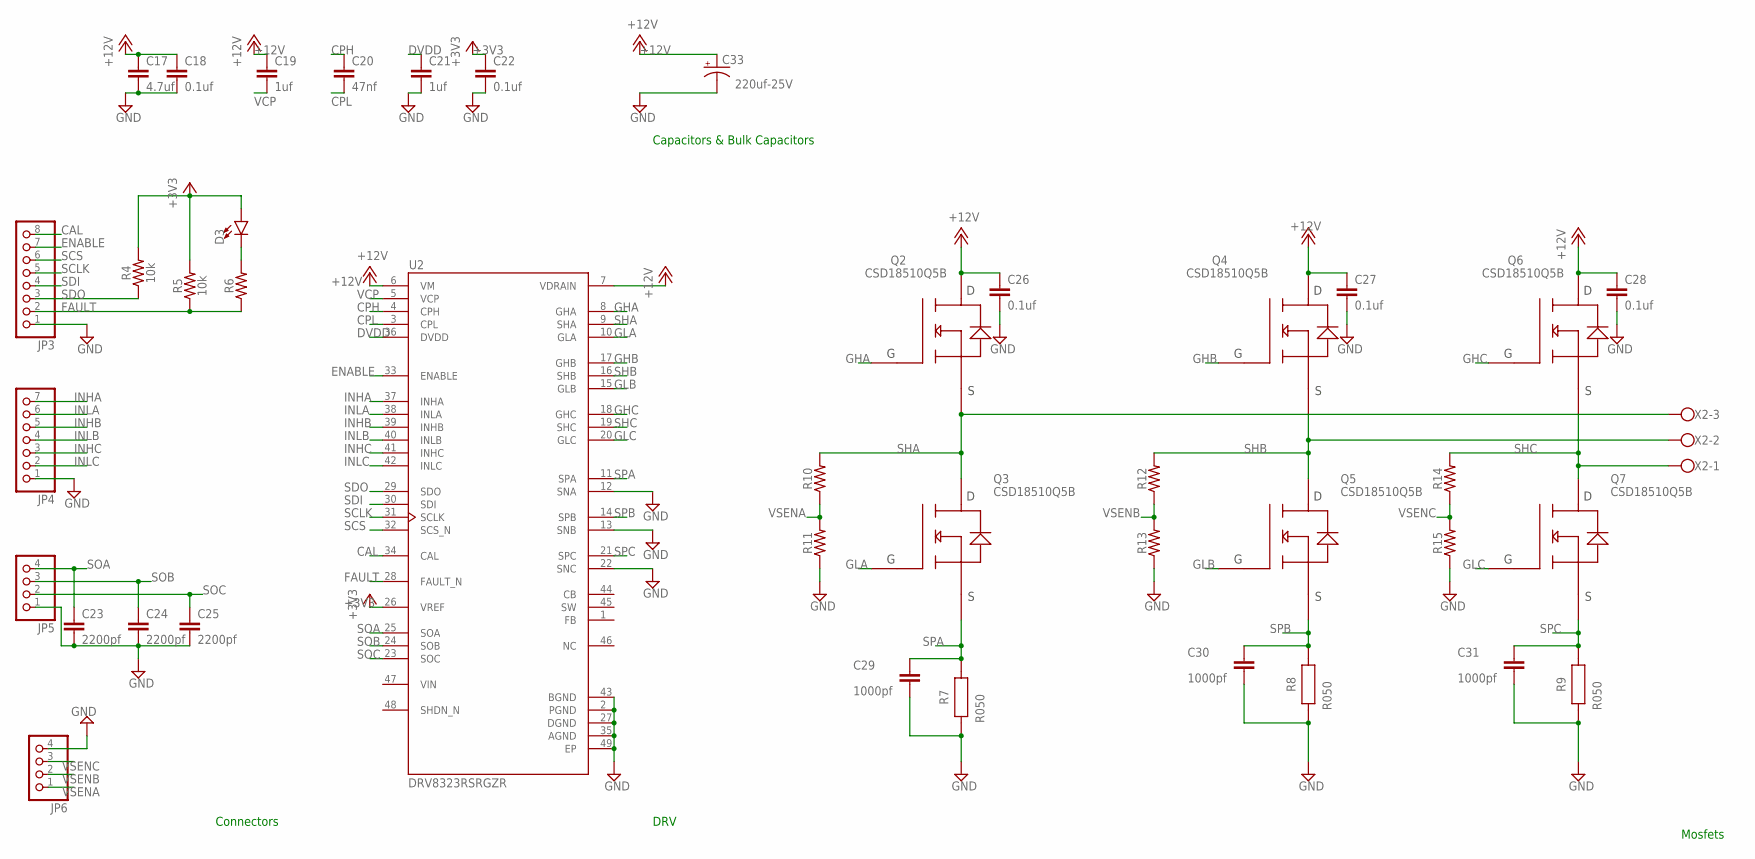
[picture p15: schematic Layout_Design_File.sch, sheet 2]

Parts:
C17: 4.7uf; 0603
C18, C22, C26, C27, C28: 0.1uf; 0603
C19, C21: 1uf; 0603
C20: 47nf; 0603
C23, C24, C25: 2200pf; 0603
C29, C30, C31: 1000pf; 0603
C33: 220uf-25V; CPOL-RADIAL-5MM-10MM-NS
D3: LED1206; LED-1206
JP3: PINHD-1X8; 1X08
JP4: PINHD-1X7; 1X07
JP5, JP6: PINHD-1X4; 1X04
Q2, Q3, Q4, Q5, Q6, Q7: CSD18510Q5B; CSD18540Q5BT
R4, R5: 10k; 0603
R6, R10, R11, R12, R13, R14, R15: 0603
R7, R8, R9: R050; WRIS_PSMC_2512_6.3X3.1X0.58X2.2(LXWXHXPW)
U2: DRV8323RSRGZR; QFN50P700X700X100-49N
X2: W237-103

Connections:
+3V3: C22.1, D3.A, R4.2, R5.2, U2.26 (VREF); also elsewhere on the board
+12V: C17.1, C18.1, C19.1, C26.1, C27.1, C28.1, C33.+, Q2.5 (D), Q2.6 (D), Q2.7 (D), Q2.8 (D), Q2.9 (D), Q4.5 (D), Q4.6 (D), Q4.7 (D), Q4.8 (D), Q4.9 (D), Q6.5 (D), Q6.6 (D), Q6.7 (D), Q6.8 (D), Q6.9 (D), U2.6 (VM), U2.7 (VDRAIN); also elsewhere on the board
CAL: JP3.8, U2.34 (CAL)
CB: U2.44 (CB)
CPH: C20.1, U2.4 (CPH)
CPL: C20.2, U2.3 (CPL)
DVDD: C21.1, U2.36 (DVDD)
ENABLE: JP3.7, U2.33 (ENABLE)
FAULT: JP3.2, R5.1, R6.1, U2.28 (FAULT_N)
GHA: Q2.4 (G), U2.8 (GHA)
GHB: Q4.4 (G), U2.17 (GHB)
GHC: Q6.4 (G), U2.18 (GHC)
GLA: Q3.4 (G), U2.10 (GLA)
GLB: Q5.4 (G), U2.15 (GLB)
GLC: Q7.4 (G), U2.20 (GLC)
GND: C17.2, C18.2, C21.2, C22.2, C23.2, C24.2, C25.2, C26.2, C27.2, C28.2, C29.2, C30.2, C31.2, C33.-, JP3.1, JP4.1, JP5.1, JP6.4, R7.1, R8.1, R9.1, R11.1, R13.1, R15.1, U2.2 (PGND), U2.12 (SNA), U2.13 (SNB), U2.22 (SNC), U2.27 (DGND), U2.35 (AGND), U2.43 (BGND), U2.49 (EP); also elsewhere on the board
INHA: JP4.7, U2.37 (INHA); also elsewhere on the board
INHB: JP4.5, U2.39 (INHB); also elsewhere on the board
INHC: JP4.3, U2.41 (INHC); also elsewhere on the board
INLA: JP4.6, U2.38 (INLA); also elsewhere on the board
INLB: JP4.4, U2.40 (INLB); also elsewhere on the board
INLC: JP4.2, U2.42 (INLC); also elsewhere on the board
unnamed: D3.C, R6.2
SCLK: JP3.5, U2.31 (SCLK); also elsewhere on the board
SCS: JP3.6, U2.32 (SCS_N); also elsewhere on the board
SDI: JP3.4, U2.30 (SDI); also elsewhere on the board
SDO: JP3.3, R4.1, U2.29 (SDO); also elsewhere on the board
SHA: Q2.1 (S), Q2.2 (S), Q2.3 (S), Q3.5 (D), Q3.6 (D), Q3.7 (D), Q3.8 (D), Q3.9 (D), R10.2, U2.9 (SHA), X2.3
SHB: Q4.1 (S), Q4.2 (S), Q4.3 (S), Q5.5 (D), Q5.6 (D), Q5.7 (D), Q5.8 (D), Q5.9 (D), R12.2, U2.16 (SHB), X2.2
SHC: Q6.1 (S), Q6.2 (S), Q6.3 (S), Q7.5 (D), Q7.6 (D), Q7.7 (D), Q7.8 (D), Q7.9 (D), R14.2, U2.19 (SHC), X2.1
SOA: C23.1, JP5.4, U2.25 (SOA)
SOB: C24.1, JP5.3, U2.24 (SOB)
SOC: C25.1, JP5.2, U2.23 (SOC)
SPA: C29.1, Q3.1 (S), Q3.2 (S), Q3.3 (S), R7.2, U2.11 (SPA)
SPB: C30.1, Q5.1 (S), Q5.2 (S), Q5.3 (S), R8.2, U2.14 (SPB)
SPC: C31.1, Q7.1 (S), Q7.2 (S), Q7.3 (S), R9.2, U2.21 (SPC)
VCP: C19.2, U2.5 (VCP)
VIN: U2.47 (VIN)
VSENA: JP6.1, R10.1, R11.2
VSENB: JP6.2, R12.1, R13.2
VSENC: JP6.3, R14.1, R15.2

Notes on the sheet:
Capacitors & Bulk Capacitors
Connectors
DRV
Mosfets

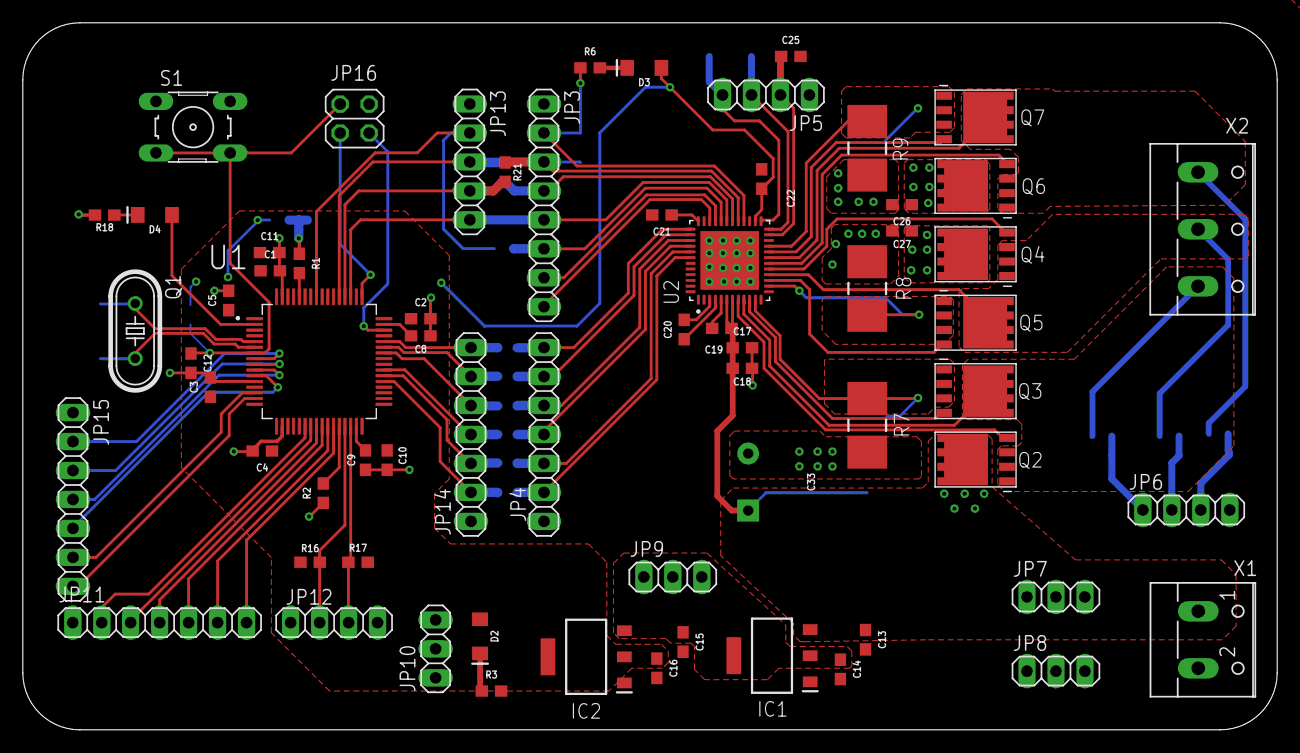
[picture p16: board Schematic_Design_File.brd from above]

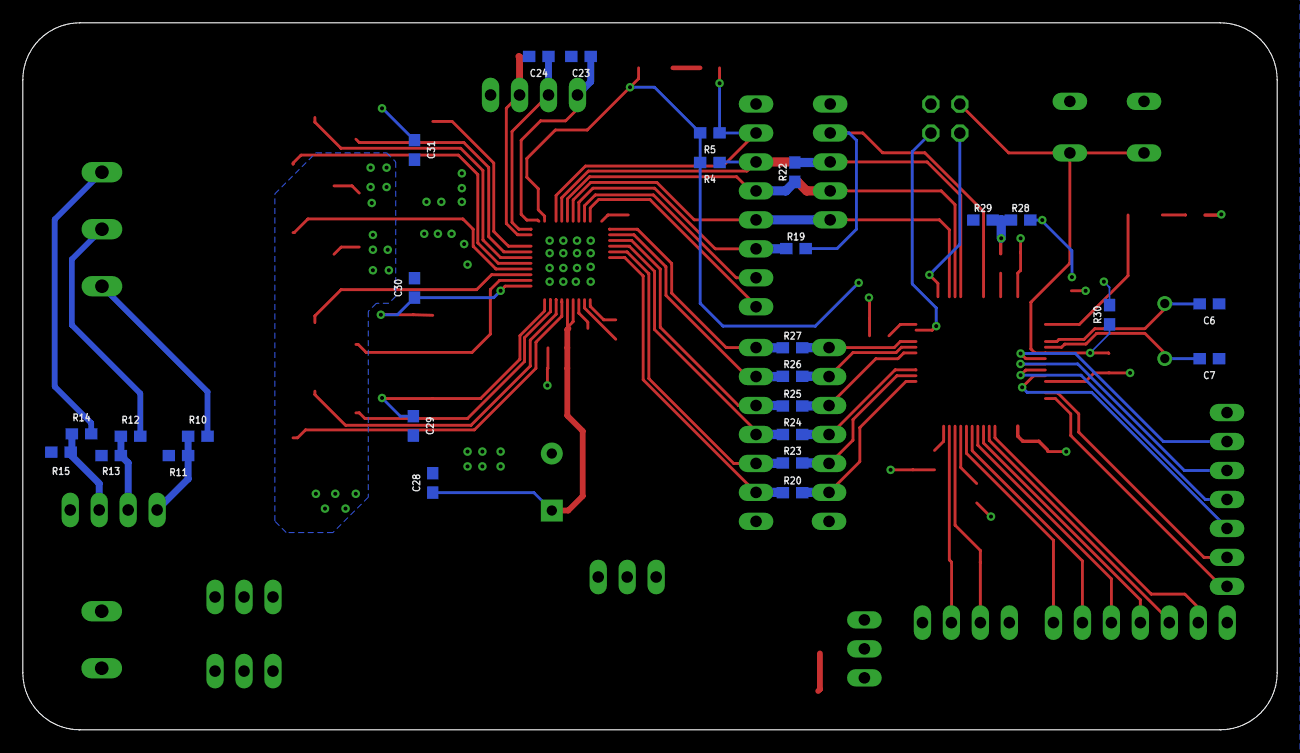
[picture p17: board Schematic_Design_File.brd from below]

Board: 2 copper layers, 110.0 x 62.0 mm, 93 parts (27 on the bottom side), 76 nets.

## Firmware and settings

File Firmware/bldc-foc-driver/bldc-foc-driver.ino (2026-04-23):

#include <SimpleFOC.h>
#define MOT1_OUT_H PA8
#define MOT2_OUT_H PA9
#define MOT3_OUT_H PA10
#define MOT1_OUT_L PA7 // PA7     //PC13
#define MOT2_OUT_L   PB0       //PA12
#define MOT3_OUT_L   PB1     //PB1       //PB15
// Motor instance
MagneticSensorI2C sensor1 = MagneticSensorI2C(AS5600_I2C);

// example of stm32 defining 2nd bus
// TwoWire Wire1(PB11, PB10);
BLDCMotor motor = BLDCMotor(7);
BLDCDriver6PWM driver = BLDCDriver6PWM(MOT1_OUT_H, MOT1_OUT_L, MOT2_OUT_H, MOT2_OUT_L, MOT3_OUT_H, MOT3_OUT_L);
// BLDCDriver6PWM driver = BLDCDriver6PWM(8, 28, 9, 29, 10, 30, 27);
// LowsideCurrentSense currentSense = LowsideCurrentSense(0.003f, -64.0f/7.0f, A_OP1_OUT, A_OP2_OUT, A_OP3_OUT);


// encoder instance 


//Encoder encoder = Encoder(A_HALL2, A_HALL3, 2048, A_HALL1);

// // Interrupt routine intialisation
// // channel A and B callbacks
// void doA(){encoder.handleA();}
// void doB(){encoder.handleB();}
// void doIndex(){encoder.handleIndex();}

// instantiate the commander
// Commander command = Commander(Serial);
// void doTarget(char* cmd) { command.motion(&motor, cmd); }

void setup() {
  
  // // initialize encoder sensor hardware
  // encoder.init();
  // encoder.enableInterrupts(doA, doB); 
  sensor1.init();
  // // link the motor to the sensor
  motor.linkSensor(&sensor1);
  
  // driver config
  // power supply voltage [V]
  driver.voltage_power_supply = 12;
  driver.init();
  // link the motor and the driver
  motor.linkDriver(&driver);
 

  // aligning voltage [V]
  motor.voltage_sensor_align = 3;
  // index search velocity [rad/s]
  motor.velocity_index_search = 3;

  // set motion control loop to be used
    motor.foc_modulation = FOCModulationType::SpaceVectorPWM;
  motor.controller = MotionControlType::velocity_openloop;

  // contoller configuration 
  // default parameters in defaults.h

  // velocity PI controller parameters
  motor.PID_velocity.P = 0.2;
  motor.PID_velocity.I = 20;
  // default voltage_power_supply
  motor.voltage_limit = 6;
  // jerk control using voltage voltage ramp
  // default value is 300 volts per sec  ~ 0.3V per millisecond
  motor.PID_velocity.output_ramp = 1000;
 
  // velocity low pass filtering time constant
  motor.LPF_velocity.Tf = 0.01;

  // angle P controller
  motor.P_angle.P = 20;
  //  maximal velocity of the position control
  motor.velocity_limit = 10;


  // use monitoring with serial 
  // Serial.begin(115200);
  // comment out if not needed
  // motor.useMonitoring(Serial);
  
  // initialize motor
  motor.init();
  // align encoder and start FOC
  motor.initFOC();


  // Serial.println(F("Motor ready."));
  // Serial.println(F("Set the target angle using serial terminal:"));
  _delay(1000);
}

void loop() {

  
  // main FOC algorithm function
  motor.loopFOC();

  // Motion control function
  motor.move(5);


}

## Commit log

2026-04-21 added hardware files
    [BOM_&_Component_selection.csv, Layout_Design_File.sch, Schematic_Design_File.brd]
2026-04-23 uploaded correct versio of firmware
    [bldc-foc-driver.ino]

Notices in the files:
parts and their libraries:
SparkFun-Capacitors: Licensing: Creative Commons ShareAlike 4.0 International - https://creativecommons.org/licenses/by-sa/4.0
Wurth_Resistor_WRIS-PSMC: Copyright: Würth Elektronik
